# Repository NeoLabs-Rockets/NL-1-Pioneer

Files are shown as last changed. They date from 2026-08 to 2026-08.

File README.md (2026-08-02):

<div align="center">

# NeoLabs-Rockets NL-1 Pioneer

NeoLabs Rockets Logo

**Rocket systems by NeoLabs — The rocket to start it all**



---

[Compatible with NeoLabs-Rockets launch system](https://github.com/NeoLabs-Rockets/Launch-System) -
[Compatible with NeoLabs-Rockets launch platform](https://github.com/NeoLabs-Rockets/Launch-Platform)

---

The **NL-1 Pioneer** is the very first rocket developed under the NeoLabs-Rockets project. Designed as an affordable and modular entry point into model rocketry, it serves as the foundation for future NeoLabs rocket designs.

This version is intentionally simple and lightweight. It is currently **non-reusable** (except in special recovery situations), as it does not yet include a parachute or other dedicated recovery system. The focus is on providing an easy-to-build, reliable platform for learning, testing, and future upgrades.

The rocket is designed to be **modular**, **low-cost**, and **easy to extend** with future payloads or recovery systems. Most parts are **print-in-place**, minimizing assembly effort while keeping the design accessible for anyone with a standard 3D printer.

</div>

<div align="center">
  
# Compatible with the following motors

| Manufacturer | Motors |
|---|---|
| Estes | 1/2A6-2, A8-3, B4-2, B6-4, B6-6, C5-3, C6-3, C6-5, C6-7 |
| Quest | A6-4, A8-3, B6-2, B6-4, C6-3, C6-5 |
| Klima | B2, B4, C6 |
| AeroTech (Q-Jet) | C12, C18, D10, D13, D20 *(some variants may be slightly longer than 70 mm)* |

</div>

# Print Settings

* **Material:** ABS is recommended for improved heat resistance and durability. PLA+ also works well for normal use.
* **Infill:** The lower, the better. **5%** is recommended to reduce weight while maintaining sufficient strength.
* **Orientation:** Print the model vertically for the best structural performance.
* **Supports:** Enable normal supports (Auto) with a **5° overhang angle**.

<div align="center">




</div>

---

<div align="center">

*Made with ❤️ by [Neo](https://github.com/neooriginal) · [NeoLabs Systems](https://github.com/NeoLabs-Systems)*

</div>

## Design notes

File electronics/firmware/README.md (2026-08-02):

# NL-1 Pioneer — Onboard Rocket Computer Firmware

Firmware for the **Seeed Studio XIAO ESP32-S3 Sense** flight computer on the NeoLabs NL-1 Pioneer. It records video and full telemetry to microSD, detects flight phases, and talks to the Mission Dashboard over a **second, independent BLE link**.

**This device never fires a motor, igniter, or any pyrotechnic.** Ignition remains exclusively with the Launch Controller.

## Hardware (from `connections.md` + schematic)

| Item | Detail |
|---|---|
| MCU | Seeed XIAO ESP32-S3 Sense (8 MB PSRAM) |
| IMU | Adafruit LSM6DSO32 (U3) |
| Baro | Adafruit BMP580 (U2) |
| I2C | SDA **GPIO5 (D4)**, SCL **GPIO6 (D5)** @ 400 kHz |
| Camera | Onboard OV2640/OV3660 (Sense expansion) |
| microSD | Onboard SPI: CS GPIO21, MOSI GPIO9, MISO GPIO8, SCK GPIO7 |
| Power | Battery → SW1 → BAT+ / BAT− |
| Battery ADC | **Not present** on schematic — not measured |

Unused sensor pins (CS, SDO, INT1/2) are left open per `connections.md`.

## Build & flash

```bash
cd electronics/firmware
pio run -e xiao_esp32s3_sense
pio run -e xiao_esp32s3_sense -t upload
pio device monitor -b 115200
```

Requirements: PlatformIO, USB cable, board in download mode if needed (BOOT + RESET).

### OTA (Bluetooth)

Same protocol shape as the Launch Controller:

| Char | UUID |
|---|---|
| OTA control | `9c4e0007-…` |
| OTA data | `9c4e0008-…` |
| OTA status | `9c4e0009-…` |

- Blocked while recording or in flight
- SHA-256 verified; device reboots after `finish`
- Dashboard: **Settings → Rocket Computer Firmware → Check & Update RC**
- CI: `.github/workflows/rc-firmware.yml` builds and publishes the rolling `rc-firmware-latest` release
- Mission Dashboard pulls from `RC_FIRMWARE_GITHUB_REPOSITORY` / `RC_FIRMWARE_RELEASE_TAG` (defaults: `NeoLabs-Rockets/NL-1-Pioneer` + `rc-firmware-latest`)

Base version: `firmware-version.txt` (CI appends `+<sha12>`).

### Host unit tests

```bash
pio test -e native_tests
```

## Architecture

```
sensor task (100 Hz)  →  flight detect  →  mission FSM
                      →  telemetry queue →  storage task → microSD
camera task           →  JPEG frames    →  storage task → video.mjpg
BLE (NimBLE)          →  command queue  →  mission FSM
                      ←  status / telemetry notifies
```

Priorities: **sensors > storage > camera/mission > BLE live telemetry**.

Modules under `src/` / `include/`:

| Module | Role |
|---|---|
| `time_manager` | Monotonic time + optional external sync |
| `mission_fsm` | Mission / recording state machine |
| `flight_detect` | Multi-criteria phase detection |
| `sensors` | LSM6DSO32 + BMP580 + MCU temp |
| `storage` | Single SD writer, session files |
| `camera_recorder` | Profiled JPEG capture with fallback |
| `ble_server` / `command_handler` | Protocol + idempotent commands |
| `event_log` | Async events.jsonl lines |

## BLE

- Device name: `NeoLabs Rocket Computer`
- Service UUID: `9c4e0001-6a2b-4c8d-9e1f-1d6c7a0b2000`  
  (Launch Controller uses `8f3a0001-…` — **separate**.)
- Command JSON (same spirit as Launch System): `{"cmd":"arm","sid":"…","seq":N}`
- File export (chunked): characteristic `9c4e0006-…` + commands `list_flights`, `list_files`, `file_begin`, `file_read`, `file_close`, `delete_flight`
- Mission Dashboard **RC Data** tab downloads a flight as ZIP over BLE, then can delete it on-device

See [docs/BLE_PROTOCOL.md](docs/BLE_PROTOCOL.md).

## Recording timeline

```
IDLE → ARM → session + video + telemetry start
     → countdown (optional) + expected ignition time
     → sensor liftoff → ascent / coast / apogee / descent
     → multi-criteria LANDING → +30 s → flush & close
```

- BLE disconnect **never** stops recording or countdown.
- `STOP_RECORDING` / `RESET` rejected during flight.
- Hard safety cap: **10 minutes** max recording if landing never confirms.
- Post-landing: **30 seconds**.

## Documentation index

- [docs/HARDWARE.md](docs/HARDWARE.md)
- [docs/ARCHITECTURE.md](docs/ARCHITECTURE.md)
- [docs/BLE_PROTOCOL.md](docs/BLE_PROTOCOL.md)
- [docs/STATE_MACHINE.md](docs/STATE_MACHINE.md)
- [docs/FLIGHT_DETECTION.md](docs/FLIGHT_DETECTION.md)
- [docs/CAMERA.md](docs/CAMERA.md)
- [docs/STORAGE.md](docs/STORAGE.md)
- [docs/DASHBOARD.md](docs/DASHBOARD.md)
- [docs/TESTING.md](docs/TESTING.md)
- [docs/ERROR_CODES.md](docs/ERROR_CODES.md)

## Dashboard

Mission Dashboard (`~/NeoLabs-Rockets/MissionDashboard`) was extended with:

- `rocket-ble-link.js` — independent GATT connection manager
- `rocket-computer.js` — UI + command mirroring
- Arm / countdown / abort on the launch console also notify the rocket computer when linked

## Safety

| Action | Rocket computer |
|---|---|
| Ignition / relay | **Never** |
| Pyro / servo deploy | **Never** |
| Video + telemetry | Yes |
| Flight phase log | Yes |
| Live BLE status | Yes (best-effort) |

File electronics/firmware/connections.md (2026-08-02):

esp32:

&#x20; board: Seeed XIAO ESP32-S3 Sense

power:

&#x20; "ESP32 3V3":

&#x20;   - "BMP580 VIN"

&#x20;   - "LSM6DSO32 VIN"

&#x20; "ESP32 GND":

&#x20;   - "BMP580 GND"

&#x20;   - "LSM6DSO32 GND"

i2c:

&#x20; "ESP32 D4 (GPIO5 / SDA)":

&#x20;   - "BMP580 SDA"

&#x20;   - "LSM6DSO32 SDA"

&#x20; "ESP32 D5 (GPIO6 / SCL)":

&#x20;   - "BMP580 SCL"

&#x20;   - "LSM6DSO32 SCL"

battery:

&#x20; "Battery +":

&#x20;   - "Switch COM"

&#x20; "Switch NO":

&#x20;   - "ESP32 BAT+"

&#x20; "Battery -":

&#x20;   - "ESP32 BAT-"

unused:

&#x20; - "BMP580 3Vo"

&#x20; - "BMP580 CS"

&#x20; - "BMP580 SDO"

&#x20; - "LSM6DSO32 INT1"

&#x20; - "LSM6DSO32 INT2"

&#x20; - "LSM6DSO32 CS"

&#x20; - "LSM6DSO32 SDO"

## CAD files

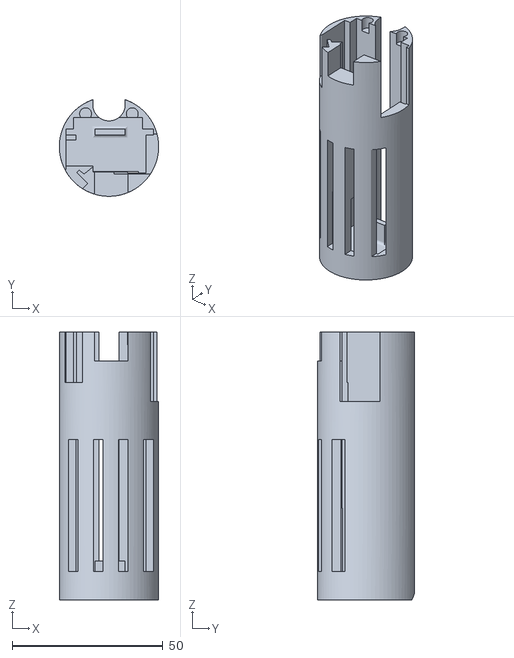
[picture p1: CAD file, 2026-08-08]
electronics/NL1-ElectronicMount.stl
33.0 x 32.1 x 89.0

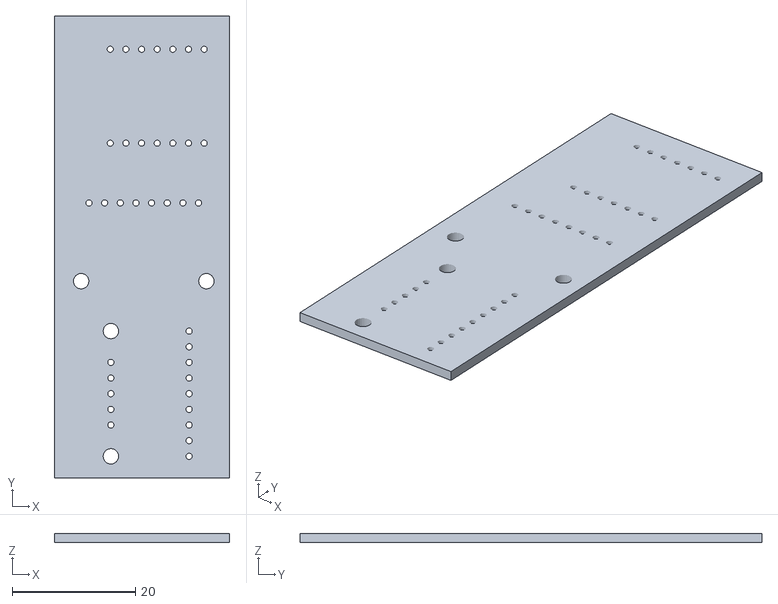
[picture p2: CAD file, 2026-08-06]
electronics/onboard-systems/pcb.stl
28.4 x 74.9 x 1.51

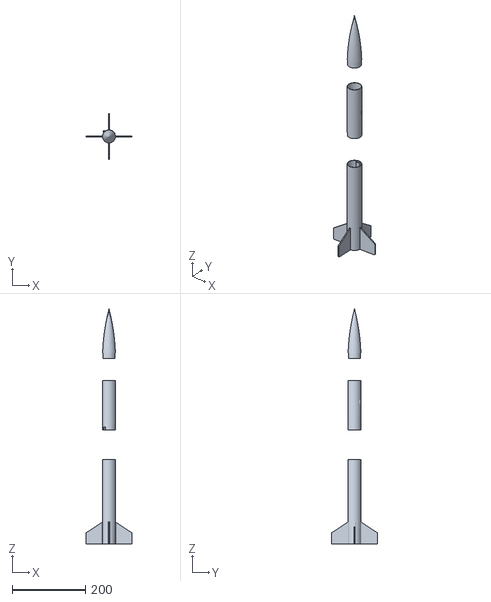
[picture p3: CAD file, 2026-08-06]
NL-1 Pioneer.stl
126.0 x 126.0 x 640.0

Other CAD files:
NL-1-Pioneer.f3d

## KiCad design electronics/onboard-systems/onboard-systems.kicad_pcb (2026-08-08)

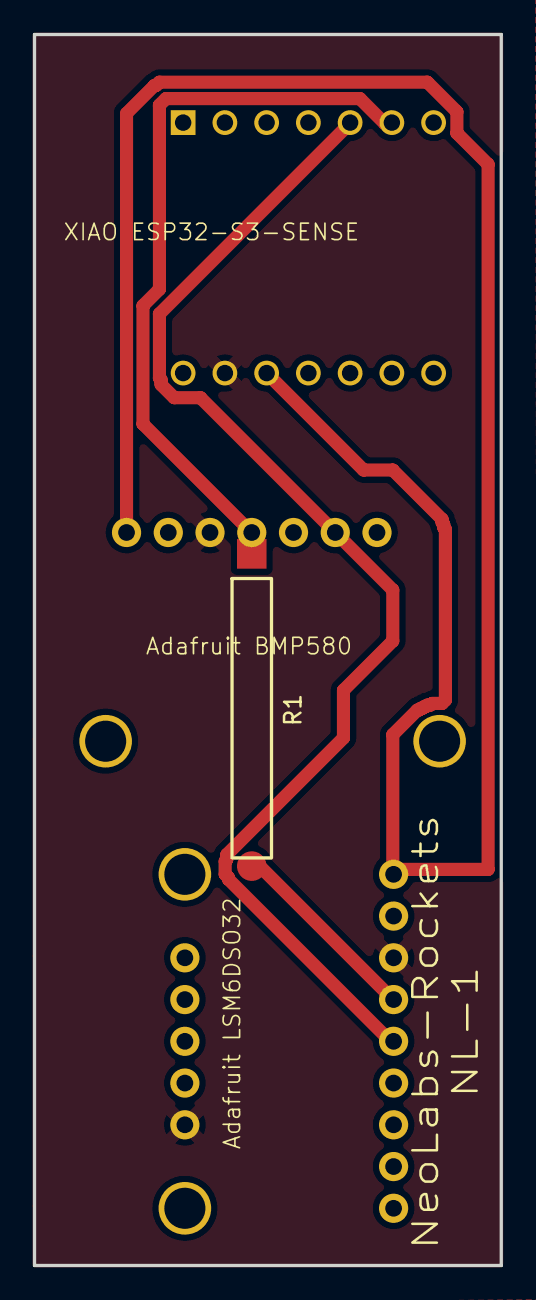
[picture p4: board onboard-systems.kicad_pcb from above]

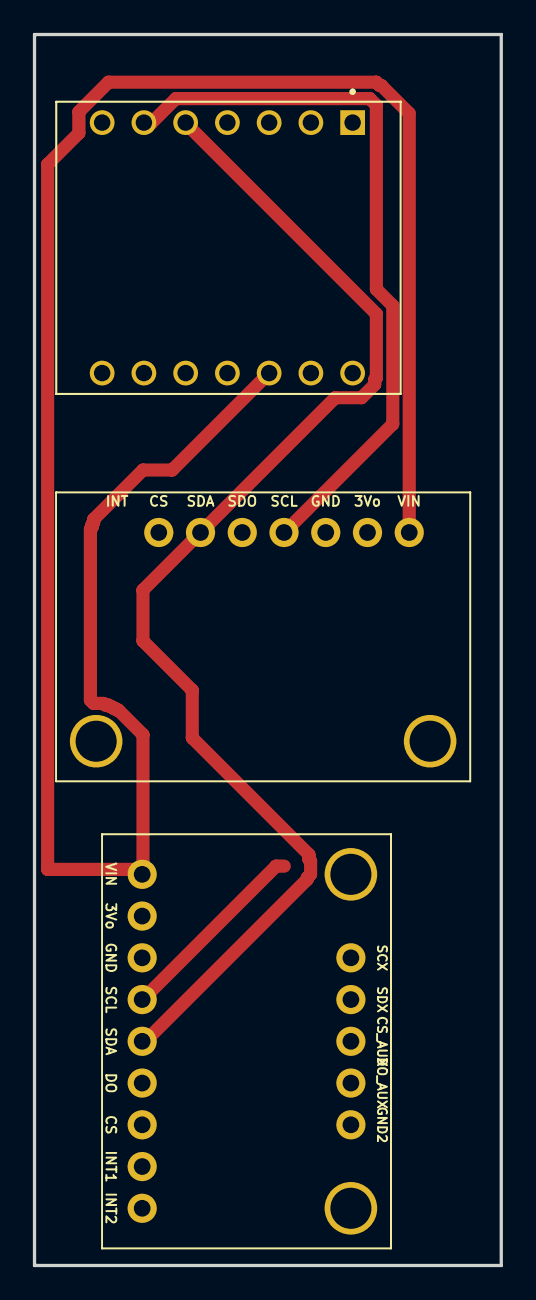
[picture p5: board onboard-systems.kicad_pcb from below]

Board: 2 copper layers, 28.4 x 74.9 mm, 4 parts (3 on the bottom side), 4 nets.

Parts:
R1: 0R; R_0R_THT_Custom
U1: XIAO_ESP32_S3; MODULE_XIAO_ESP32_S3
U2: Adafruit_BMP580; Adafruit_BMP580_Breakout
U3: Adafruit_LSM6DSO32; Adafruit_LSM6DSO32_Breakout

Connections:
GND: U1.13 (GND), U2.3 (GND), U3.3 (GND), U3.14 (GND2)
unnamed: U1.12 (3V3), U2.1 (VIN), U3.1 (VIN)
unnamed: U1.5 (D4/GPIO5), U2.6 (SDA), U3.5 (SDA)
unnamed: R1.1, U1.6 (D5/GPIO6), U2.4 (SCL), U3.4 (SCL)

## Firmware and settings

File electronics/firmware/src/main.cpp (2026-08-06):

/**
 * NeoLabs NL-1 Pioneer — Onboard Rocket Computer
 *
 * Records video + telemetry to microSD. Communicates with Mission Dashboard
 * over BLE. Never controls ignition or pyrotechnics.
 *
 * Hardware (connections.md + schematic):
 *   Seeed XIAO ESP32-S3 Sense
 *   BMP580 + LSM6DSO32 on I2C GPIO5/GPIO6
 *   Onboard camera + microSD
 */

#include <Arduino.h>
#include <esp_task_wdt.h>
#include <esp_system.h>

#include "config.h"
#include "board_pins.h"
#include "types.h"
#include "time_manager.h"
#include "event_log.h"
#include "mission_fsm.h"
#include "mission_fsm_internal.h"
#include "sensors.h"
#include "flight_detect.h"
#include "storage.h"
#include "camera_recorder.h"
#include "ble_server.h"
#include "ota_service.h"
#include "crc16.h"

static SensorSnapshot g_sensors{};
static SystemSnapshot g_system{};
static portMUX_TYPE g_snap_mux = portMUX_INITIALIZER_UNLOCKED;

// ── Status LED (XIAO amber user LED, GPIO21, active-low) ────────────────────
// On Sense, GPIO21 is also microSD CS. Never drive it as an LED — any
// pre-mount bit-banging of CS contributes to "Card Failed! cmd: 0x00".
#if USER_LED_AVAILABLE
static void statusLedInit() {}
static void statusLedBootFlash() {}
static void statusLedReleaseForSd() {
  // Leave CS idle high before Storage::begin claims it.
  pinMode(PIN_SD_CS, OUTPUT);
  digitalWrite(PIN_SD_CS, HIGH);
}
static void statusLedHeartbeat() {}
#else
static void statusLedInit() {}
static void statusLedBootFlash() {}
static void statusLedReleaseForSd() {}
static void statusLedHeartbeat() {}
#endif

static void fillSystemSnapshot() {
  CameraRecorder::Stats cs = CameraRecorder::stats();
  g_system.mission = MissionFsm::state();
  g_system.recording = MissionFsm::recordingState();
  g_system.storage = Storage::state();
  g_system.bluetooth = BleServer::state();
  g_system.camera = CameraRecorder::state();
  g_system.phase = FlightDetect::phase();
  g_system.uptime_ms = static_cast<uint32_t>(TimeManager::monoMs());
  g_system.countdown_left_ms = MissionFsm::countdownRemainingMs(TimeManager::monoMs());
  g_system.expected_ignition_mono_ms = MissionFsm::expectedIgnitionMonoMs();
  g_system.actual_liftoff_mono_ms = MissionFsm::actualLiftoffMonoMs();
  g_system.frames_written = cs.frames_written;
  g_system.frames_dropped = cs.frames_dropped;
  g_system.actual_fps = cs.actual_fps;
  g_system.free_sd_bytes = Storage::freeBytes();
  g_system.session_bytes = 0;
  g_system.camera_profile = static_cast<uint8_t>(cs.profile);
  g_system.ground_test = false;
  g_system.last_error[0] = '\0';
  g_system.last_warning[0] = '\0';
}

static void buildTelemetryRecord(TelemetryRecord& rec, uint32_t seq) {
  TimeStamp ts = TimeManager::now();
  memset(&rec, 0, sizeof(rec));
  rec.magic = TELEM_MAGIC;
  rec.version = 1;
  rec.size = sizeof(TelemetryRecord);
  rec.mono_us = ts.mono_us;
  rec.session_us = ts.session_us;
  rec.sync_unix_ms = ts.sync_unix_ms;
  portENTER_CRITICAL(&g_snap_mux);
  rec.ax = g_sensors.ax;
  rec.ay = g_sensors.ay;
  rec.az = g_sensors.az;
  rec.gx = g_sensors.gx;
  rec.gy = g_sensors.gy;
  rec.gz = g_sensors.gz;
  rec.accel_mag = g_sensors.accel_mag;
  rec.pressure_pa = g_sensors.pressure_pa;
  rec.altitude_m = g_sensors.altitude_m;
  rec.vert_vel_ms = g_sensors.vert_vel_ms;
  rec.temp_bmp_c = g_sensors.temps[0].valid ? g_sensors.temps[0].celsius : NAN;
  rec.temp_imu_c = g_sensors.temps[1].valid ? g_sensors.temps[1].celsius : NAN;
  rec.temp_mcu_c = g_sensors.temps[2].valid ? g_sensors.temps[2].celsius : NAN;
  uint8_t flags = 0;
  if (g_sensors.imu_health == SensorHealth::OK) flags |= 1;
  if (g_sensors.baro_health == SensorHealth::OK) flags |= 2;
  if (CameraRecorder::state() == CameraState::RECORDING
      || CameraRecorder::state() == CameraState::READY
      || CameraRecorder::state() == CameraState::FALLBACK) flags |= 4;
  if (Storage::state() == StorageState::MOUNTED || Storage::state() == StorageState::WRITING) flags |= 8;
  portEXIT_CRITICAL(&g_snap_mux);
  rec.mission_state = static_cast<uint8_t>(MissionFsm::state());
  rec.recording_state = static_cast<uint8_t>(MissionFsm::recordingState());
  rec.flight_phase = static_cast<uint8_t>(FlightDetect::phase());
  rec.flags = flags;
  CameraRecorder::Stats cs = CameraRecorder::stats();
  rec.frame_count = cs.frames_written;
  rec.actual_fps_x10 = static_cast<uint16_t>(cs.actual_fps * 10.f);
  rec.dropped_frames = static_cast<uint16_t>(min(cs.frames_dropped, 65535u));
  rec.free_sd_kb = static_cast<uint32_t>(Storage::freeBytes() / 1024ULL);
  rec.seq = seq;
  rec.crc16 = crc16_ccitt(reinterpret_cast<const uint8_t*>(&rec),
                          sizeof(TelemetryRecord) - sizeof(uint16_t));
}

static void logResetReason() {
  esp_reset_reason_t r = esp_reset_reason();
  const char* name = "UNKNOWN";
  switch (r) {
    case ESP_RST_POWERON: name = "POWERON"; break;
    case ESP_RST_SW: name = "SW"; break;
    case ESP_RST_PANIC: name = "PANIC"; break;
    case ESP_RST_INT_WDT: name = "INT_WDT"; break;
    case ESP_RST_TASK_WDT: name = "TASK_WDT"; break;
    case ESP_RST_WDT: name = "WDT"; break;
    case ESP_RST_BROWNOUT: name = "BROWNOUT"; break;
    case ESP_RST_SDIO: name = "SDIO"; break;
    default: break;
  }
  char msg[48];
  snprintf(msg, sizeof(msg), "reset_%s", name);
  EventLog::emit(EventType::RESET_REASON, msg);
  EventLog::emit(EventType::BOOT, FIRMWARE_VERSION);
}

// ── Tasks ───────────────────────────────────────────────────────────────────

static void sensorTask(void*) {
  // Subscribe before the loop: esp_task_wdt_reset() is a no-op (ESP_ERR_NOT_FOUND)
  // for any task that was never added, so an unsubscribed task is unmonitored.
  esp_task_wdt_add(nullptr);
  const TickType_t period = pdMS_TO_TICKS(1000 / SENSOR_HZ_IMU);
  TickType_t last = xTaskGetTickCount();
  uint32_t telem_div = 0;
  uint32_t seq = 0;
  for (;;) {
    SensorSnapshot s;
    if (Sensors::sample(s)) {
      portENTER_CRITICAL(&g_snap_mux);
      g_sensors = s;
      portEXIT_CRITICAL(&g_snap_mux);

      bool care = MissionFsm::countdownActive()
                  || MissionFsm::state() == MissionState::ARMED
                  || MissionFsm::state() == MissionState::RECORDING
                  || MissionFsm::state() == MissionState::COUNTDOWN
                  || MissionFsm::state() == MissionState::IGNITION_EXPECTED
                  || MissionFsm::hasLiftedOff();
      if (FlightDetect::update(s, MissionFsm::expectedIgnitionMonoMs(), care)) {
        MissionFsm::setFlightPhase(FlightDetect::phase(), "sensor");
      }

      // Log telemetry at TELEMETRY_LOG_HZ when session open
      telem_div++;
      if (telem_div >= (SENSOR_HZ_IMU / TELEMETRY_LOG_HZ)) {
        telem_div = 0;
        if (Storage::isSessionOpen()) {
          TelemetryRecord rec;
          buildTelemetryRecord(rec, seq++);
          Storage::enqueueTelemetry(rec);
        }
      }
    }
    esp_task_wdt_reset();
    vTaskDelayUntil(&last, period);
  }
}

static void storageTask(void*) {
  esp_task_wdt_add(nullptr);
  for (;;) {
    // Session start/stop driven by mission flags
    char reason[40];
    if (MissionFsm::consumeStartRecording(reason, sizeof(reason))) {
      if (!Storage::isSessionOpen()) {
        if (Storage::openSession(reason)) {
          CameraRecorder::start();
          MissionFsm::markRecordingActive();
        } else {
          MissionFsm::markRecordingFailed();
          EventLog::emit(EventType::STORAGE_FAULT, "session_open_failed");
        }
      } else {
        // Idempotent — already recording
        MissionFsm::markRecordingActive();
      }
    }
    if (MissionFsm::consumeStopRecording()) {
      CameraRecorder::stop();
      Storage::closeSession("stop");
      MissionFsm::markRecordingStopped();
    }
    Storage::taskLoop();
    esp_task_wdt_reset();
    vTaskDelay(pdMS_TO_TICKS(5));
  }
}

static void cameraTask(void*) {
  esp_task_wdt_add(nullptr);
  for (;;) {
    if (CameraRecorder::isRecording()) {
      CameraRecorder::service();
    }
    esp_task_wdt_reset();
    vTaskDelay(pdMS_TO_TICKS(5));
  }
}

static void missionTask(void*) {
  esp_task_wdt_add(nullptr);
  uint32_t last_status_ms = 0;
  for (;;) {
    BleServer::serviceCommands();
    OtaService::loop();
    MissionFsm::tick(TimeManager::monoMs());

    fillSystemSnapshot();

    uint32_t now = static_cast<uint32_t>(TimeManager::monoMs());
    SensorSnapshot sensors;
    portENTER_CRITICAL(&g_snap_mux);
    sensors = g_sensors;
    portEXIT_CRITICAL(&g_snap_mux);

    // Status every 1 s; telemetry at configured rate
    if (now - last_status_ms >= 1000) {
      last_status_ms = now;
      BleServer::publishStatus(g_system, sensors);
    }
    BleServer::publishTelemetry(sensors, g_system);

    // Shed BLE telemetry rate if SD is falling behind (simple heuristic)
    CameraRecorder::Stats cs = CameraRecorder::stats();
    if (cs.frames_dropped > 0 && cs.frames_written > 0
        && cs.frames_dropped * 10 > cs.frames_written) {
      BleServer::setTelemetryHz(BLE_TELEMETRY_HZ_MIN);
    }

    esp_task_wdt_reset();
    vTaskDelay(pdMS_TO_TICKS(20));
  }
}

void setup() {
  Serial.begin(115200);
  delay(200);
  Serial.printf("\n[NL1] Rocket Computer %s\n", FIRMWARE_VERSION);

  // Visual proof-of-life before SD claims GPIO21 as CS.
  statusLedInit();
  statusLedBootFlash();

  TimeManager::begin();
  EventLog::begin();
  MissionFsm::begin();
  MissionFsm::advanceFromBoot();
  logResetReason();

  // Task watchdog (timeout seconds, panic on trip)
  esp_task_wdt_init(WDT_TIMEOUT_S, true);
  esp_task_wdt_add(NULL);

  // Release GPIO21 to SD CS before mounting the card.
  statusLedReleaseForSd();
  bool sd_ok = Storage::begin();

  // Camera SCCB (pins 39/40) shares the ESP32-S3 I2C controller with Wire.
  // If sensors are brought up first, esp_camera_init() leaves external I2C
  // (GPIO5/6) broken — scan/begin OK, then continuous Wire Error -1.
  // Init camera first, then external sensors on Wire.
  bool cam_ok = CameraRecorder::begin();
  bool sens_ok = Sensors::begin();
  FlightDetect::begin();
  BleServer::begin();

  if (!sens_ok) EventLog::emit(EventType::WARNING, "no_sensors");
  if (!sd_ok) EventLog::emit(EventType::WARNING, "no_sd");
  if (!cam_ok) EventLog::emit(EventType::WARNING, "no_camera");

  // Self-test complete — enter IDLE even if some peripherals missing (degraded)
  MissionFsm::advanceSelfTestOk();

  xTaskCreatePinnedToCore(sensorTask, "sensor", 6144, nullptr, PRIO_SENSOR, nullptr, 1);
  xTaskCreatePinnedToCore(storageTask, "storage", 8192, nullptr, PRIO_STORAGE, nullptr, 1);
  xTaskCreatePinnedToCore(cameraTask, "camera", 8192, nullptr, PRIO_CAMERA, nullptr, 0);
  xTaskCreatePinnedToCore(missionTask, "mission", 8192, nullptr, PRIO_MISSION, nullptr, 0);

  Serial.println("[NL1] ready — advertising as NeoLabs Rocket Computer");
  Serial.printf("[NL1] SD=%d (free=%llu MB) IMU=%d BARO=%d CAM=%d\n",
                sd_ok,
                static_cast<unsigned long long>(Storage::freeBytes() / (1024ULL * 1024ULL)),
                Sensors::imuPresent(), Sensors::baroPresent(), cam_ok);
  Serial.printf("[NL1] storage_state=%d camera_state=%d\n",
                static_cast<int>(Storage::state()),
                static_cast<int>(CameraRecorder::state()));
}

void loop() {
  statusLedHeartbeat();
  OtaService::loop();
  esp_task_wdt_reset();
  vTaskDelay(pdMS_TO_TICKS(20));
}

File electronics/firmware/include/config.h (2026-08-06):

#pragma once
/**
 * Central configuration for NL-1 onboard rocket computer.
 * Thresholds, rates, camera profiles, and safety timeouts live here.
 */

#include <stddef.h>
#include <stdint.h>
#include "board_pins.h"

#ifndef FIRMWARE_VERSION
#define FIRMWARE_VERSION "1.0.0"
#endif

#define PROTOCOL_VERSION_MAJOR 1
#define PROTOCOL_VERSION_MINOR 0

// ── Task priorities (higher = more important) ───────────────────────────────
// Priority order from requirements:
//   1 sensors  2 storage  3 video  4 state machine  5 BLE telemetry
static constexpr uint8_t PRIO_SENSOR   = 5;
static constexpr uint8_t PRIO_STORAGE  = 4;
static constexpr uint8_t PRIO_CAMERA   = 3;
static constexpr uint8_t PRIO_MISSION  = 3;
static constexpr uint8_t PRIO_BLE      = 2;
static constexpr uint8_t PRIO_WATCHDOG = 1;

// ── Sampling rates ──────────────────────────────────────────────────────────
static constexpr uint32_t SENSOR_HZ_IMU       = 100;  // LSM6DSO32 sample target
static constexpr uint32_t SENSOR_HZ_BARO      = 50;   // BMP580 sample target
static constexpr uint32_t SENSOR_HZ_TEMP_MCU  = 1;
static constexpr uint32_t TELEMETRY_LOG_HZ    = 50;   // written to SD
static constexpr uint32_t BLE_TELEMETRY_HZ    = 5;    // live stream (degrades first)
static constexpr uint32_t BLE_TELEMETRY_HZ_MIN = 1;

// ── Camera profiles (highest stable first; runtime may fall back) ───────────
// "Max" is not the nominal peak resolution — it is the highest stable combo of
// resolution × fps × JPEG quality under concurrent sensor+SD+BLE load.
// Default primary profile: SVGA 800×600 @ 12 fps, JPEG quality 12, 2 FB in PSRAM.
// Expected data rate ≈ 0.4–0.9 MB/s depending on scene complexity.
enum class CameraProfileId : uint8_t {
  Primary_SVGA_12 = 0,
  Fallback_VGA_10 = 1,
  Low_QVGA_10     = 2,
  Count
};

// frame sizes match esp32-camera framesize_t
#define CAM_FRAMESIZE_SVGA  8   // 800x600
#define CAM_FRAMESIZE_VGA   6   // 640x480
#define CAM_FRAMESIZE_QVGA  5   // 320x240

// ── Recording / mission timeouts ────────────────────────────────────────────
// Model rocket motor burn + coast for NL-1 class motors is typically < 30 s.
// Conservative max flight window before force-stop if landing never confirms.
static constexpr uint32_t POST_LANDING_RECORD_MS     = 30000;   // +30 s after LANDED
static constexpr uint32_t MAX_MISSION_RECORD_MS      = 600000;  // 10 min hard safety cap
static constexpr uint32_t RECORDING_LEAD_BEFORE_IGN_MS = 30000;  // must be recording ≥30 s before ign
static constexpr uint32_t SD_FLUSH_INTERVAL_MS        = 1000;
static constexpr uint32_t SD_MIN_FREE_BYTES           = 32UL * 1024UL * 1024UL;  // refuse new session if <32 MB

// ── Flight phase detection (multi-criteria, hysteresis) ─────────────────────
// Accelerations in m/s², rates in deg/s, altitudes in m, velocities in m/s.
struct FlightDetectConfig {
  float liftoffAccelMagMs2;
  float liftoffAxialDeltaMs2;
  uint32_t liftoffMinMs;
  float burnoutAccelMs2;
  uint32_t burnoutMinMs;
  float apogeeVertVelMs;
  float apogeeAltWindowM;
  uint32_t apogeeMinMs;
  float descentVertVelMs;
  float impactAccelMagMs2;
  uint32_t impactWindowMs;
  float landedAccelBandMs2;
  float landedGyroMaxDps;
  float landedAltStdM;
  float landedVertVelMs;
  uint32_t landedConfirmMs;
  float minFlightAltGainM;
};

static constexpr FlightDetectConfig kFlightCfg = {
  /*liftoffAccelMagMs2*/   18.0f,
  /*liftoffAxialDeltaMs2*/ 12.0f,
  /*liftoffMinMs*/         80,
  /*burnoutAccelMs2*/      14.0f,
  /*burnoutMinMs*/         150,
  /*apogeeVertVelMs*/      2.5f,
  /*apogeeAltWindowM*/     3.0f,
  /*apogeeMinMs*/          200,
  /*descentVertVelMs*/     -2.0f,
  /*impactAccelMagMs2*/    25.0f,
  /*impactWindowMs*/       50,
  /*landedAccelBandMs2*/   2.5f,
  /*landedGyroMaxDps*/     15.0f,
  /*landedAltStdM*/        1.5f,
  /*landedVertVelMs*/      1.0f,
  /*landedConfirmMs*/      2500,
  /*minFlightAltGainM*/    5.0f,
};
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

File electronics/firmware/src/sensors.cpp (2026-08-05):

#include "sensors.h"
#include "board_pins.h"
#include "time_manager.h"
#include "event_log.h"
#include "config.h"

#ifndef UNIT_TEST
#include <Wire.h>
#include <Adafruit_LSM6DSO32.h>
#include <Adafruit_BMP5xx.h>
#include <esp_system.h>
#endif

#include <math.h>
#include <string.h>

namespace Sensors {
namespace {

#ifndef UNIT_TEST
Adafruit_LSM6DSO32 lsm;
Adafruit_BMP5xx bmp;
#endif

bool imu_ok = false;
bool baro_ok = false;
SensorHealth imu_h = SensorHealth::MISSING;
SensorHealth baro_h = SensorHealth::MISSING;

float sea_level_pa = 101325.f;
float last_alt = NAN;
uint64_t last_alt_us = 0;
float vert_vel = 0;
float filt_ax = 0, filt_ay = 0, filt_az = 0;

bool sim_enabled = false;
SensorSnapshot sim_sample{};

float pressureToAltitude(float pa) {
  // International Standard Atmosphere approximation
  return 44330.f * (1.f - powf(pa / sea_level_pa, 0.1903f));
}

#ifndef UNIT_TEST
float readMcuTempC() {
  // ESP32-S3 internal temperature sensor (°C).
  return temperatureRead();
}
#endif

}  // namespace

#ifndef UNIT_TEST
// Scan 7-bit addresses and print responders for bring-up / wiring debug.
static int i2cScanAndLog(const char* tag, int sda, int scl, uint32_t hz) {
  Wire.end();
  // Weak internal pull-ups help if external STEMMA pull-ups are missing.
  pinMode(sda, INPUT_PULLUP);
  pinMode(scl, INPUT_PULLUP);
  delay(2);
  int sda_lvl = digitalRead(sda);
  int scl_lvl = digitalRead(scl);
  Serial.printf("[NL1] I2C %s SDA=GPIO%d SCL=GPIO%d @ %lu Hz (idle SDA=%d SCL=%d, expect 1/1)\n",
                tag, sda, scl, static_cast<unsigned long>(hz), sda_lvl, scl_lvl);

  Wire.begin(sda, scl);
  Wire.setClock(hz);
  delay(20);

  int found = 0;
  for (uint8_t addr = 0x08; addr < 0x78; addr++) {
    Wire.beginTransmission(addr);
    uint8_t err = Wire.endTransmission();
    if (err == 0) {
      found++;
      const char* who = "";
      if (addr == ADDR_BMP580 || addr == ADDR_BMP580_ALT) who = " (BMP580?)";
      else if (addr == ADDR_LSM6DSO32 || addr == ADDR_LSM6DSO32_ALT) who = " (LSM6DSO32?)";
      Serial.printf("[NL1]   I2C device at 0x%02X%s\n", addr, who);
    }
  }
  if (found == 0) {
    Serial.println("[NL1]   I2C: no devices responded");
  } else {
    Serial.printf("[NL1]   I2C: %d device(s) found\n", found);
  }
  return found;
}
#endif

bool begin() {
  imu_ok = false;
  baro_ok = false;
  imu_h = SensorHealth::MISSING;
  baro_h = SensorHealth::MISSING;
  last_alt = NAN;
  vert_vel = 0;
  sim_enabled = false;

#ifndef UNIT_TEST
  // PCB nets (onboard-systems.kicad_pcb):
  //   SDA = U1 D4/GPIO5 → U2.SDA + U3.SDA
  //   SCL = U1 D5/GPIO6 → U2.SCL + U3.SCL
  //   VIN = U1 3V3
  // Try 100 kHz first (more tolerant of capacitance / weak pull-ups), then 400 kHz.
  int found = i2cScanAndLog("primary", PIN_I2C_SDA, PIN_I2C_SCL, 100000);
  if (found == 0) {
    found = i2cScanAndLog("primary-400k", PIN_I2C_SDA, PIN_I2C_SCL, I2C_FREQ_HZ);
  }
  if (found == 0) {
    // Diagnostic only: detect SDA/SCL swap on a hand-wired board.
    found = i2cScanAndLog("swapped", PIN_I2C_SCL, PIN_I2C_SDA, 100000);
    if (found > 0) {
      Serial.println("[NL1] WARNING: devices only visible with SDA/SCL swapped!");
    } else {
      // Restore primary pin map for library probes below.
      Wire.end();
      Wire.begin(PIN_I2C_SDA, PIN_I2C_SCL);
      Wire.setClock(100000);
    }
  }

  delay(50);  // allow breakouts to come out of power-on reset

  // LSM6DSO32 — try both address straps
  if (lsm.begin_I2C(ADDR_LSM6DSO32, &Wire) || lsm.begin_I2C(ADDR_LSM6DSO32_ALT, &Wire)) {
    lsm.setAccelRange(LSM6DSO32_ACCEL_RANGE_32_G);
    lsm.setGyroRange(LSM6DS_GYRO_RANGE_2000_DPS);
    lsm.setAccelDataRate(LSM6DS_RATE_104_HZ);
    lsm.setGyroDataRate(LSM6DS_RATE_104_HZ);
    imu_ok = true;
    imu_h = SensorHealth::OK;
    Serial.println("[NL1] LSM6DSO32 OK");
  } else {
    EventLog::emit(EventType::SENSOR_FAULT, "LSM6DSO32_missing");
    imu_h = SensorHealth::MISSING;
    Serial.println("[NL1] LSM6DSO32 MISSING");
  }

  // BMP580 (Adafruit_BMP5xx: pressure field is hPa after performReading)
  if (bmp.begin(ADDR_BMP580, &Wire) || bmp.begin(ADDR_BMP580_ALT, &Wire)) {
    bmp.setOutputDataRate(BMP5XX_ODR_50_HZ);
    bmp.setPowerMode(BMP5XX_POWERMODE_NORMAL);
    baro_ok = true;
    baro_h = SensorHealth::OK;
    Serial.println("[NL1] BMP580 OK");
  } else {
    EventLog::emit(EventType::SENSOR_FAULT, "BMP580_missing");
    baro_h = SensorHealth::MISSING;
    Serial.println("[NL1] BMP580 MISSING");
  }
#else
  imu_ok = true;
  baro_ok = true;
  imu_h = SensorHealth::OK;
  baro_h = SensorHealth::OK;
#endif

  return imu_ok || baro_ok;
}

void end() {}

bool sample(SensorSnapshot& out) {
  if (sim_enabled) {
    out = sim_sample;
    out.ts = TimeManager::now();
    out.valid = true;
    return true;
  }

  memset(&out, 0, sizeof(out));
  out.ts = TimeManager::now();
  out.imu_health = imu_h;
  out.baro_health = baro_h;
  out.valid = false;
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

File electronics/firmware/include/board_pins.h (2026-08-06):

#pragma once
/**
 * Hardware pin map for NL-1 Pioneer onboard rocket computer.
 *
 * Sources of truth (do not invent pins):
 *   - electronics/firmware/connections.md
 *   - electronics/onboard-systems/onboard-systems.kicad_sch
 *   - Seeed Studio XIAO ESP32-S3 Sense official pinout
 *
 * External sensors on shared I2C bus:
 *   BMP580  (U2) — pressure + temperature
 *   LSM6DSO32 (U3) — accel + gyro (+ IMU die temperature)
 *
 * Onboard Sense expansion (camera + microSD) uses fixed GPIOs documented by Seeed.
 */

#include <stdint.h>

// ── Board identity ──────────────────────────────────────────────────────────
#define BOARD_MODEL_NAME        "Seeed XIAO ESP32-S3 Sense"
#define CAMERA_MODEL_NAME       "OV2640/OV3660 (XIAO Sense expansion)"
#define HAS_PSRAM_EXPECTED      1
#define PSRAM_SIZE_BYTES_EXPECT (8 * 1024 * 1024)

// ── External I2C bus (connections.md) ───────────────────────────────────────
// ESP32 D4 = GPIO5 = SDA
// ESP32 D5 = GPIO6 = SCL
static constexpr int PIN_I2C_SDA = 5;
static constexpr int PIN_I2C_SCL = 6;
static constexpr uint32_t I2C_FREQ_HZ = 400000;

// Default 7-bit addresses for Adafruit STEMMA QT breakouts (I2C mode, SDO unused)
// Adafruit_BMP5xx: DEFAULT 0x46, ALTERNATIVE 0x47
static constexpr uint8_t ADDR_BMP580     = 0x46;
static constexpr uint8_t ADDR_BMP580_ALT = 0x47;
static constexpr uint8_t ADDR_LSM6DSO32  = 0x6A;  // Adafruit default
static constexpr uint8_t ADDR_LSM6DSO32_ALT = 0x6B;

// ── Onboard microSD (XIAO ESP32-S3 Sense) ───────────────────────────────────
// Seeed wiki: CS=GPIO21, SCK=D8/GPIO7, MISO=D9/GPIO8, MOSI=D10/GPIO9.
// Matches variants/XIAO_ESP32S3/pins_arduino.h (MOSI/MISO/SCK defaults).
// Init with default SPI + SD.begin(21) — not a custom SPIClass(FSPI).
static constexpr int PIN_SD_CS   = 21;
static constexpr int PIN_SD_MOSI = 9;   // D10
static constexpr int PIN_SD_MISO = 8;   // D9
static constexpr int PIN_SD_SCK  = 7;   // D8

// ── Onboard camera (XIAO ESP32-S3 Sense expansion) ──────────────────────────
// Confirmed against Seeed camera pin table (GPIO occupancy of Sense board).
static constexpr int CAM_PIN_PWDN  = -1;
static constexpr int CAM_PIN_RESET = -1;
static constexpr int CAM_PIN_XCLK  = 10;
static constexpr int CAM_PIN_SIOD  = 40;
static constexpr int CAM_PIN_SIOC  = 39;
static constexpr int CAM_PIN_D7    = 48;  // Y9
static constexpr int CAM_PIN_D6    = 11;  // Y8
static constexpr int CAM_PIN_D5    = 12;  // Y7
static constexpr int CAM_PIN_D4    = 14;  // Y6
static constexpr int CAM_PIN_D3    = 16;  // Y5
static constexpr int CAM_PIN_D2    = 18;  // Y4
static constexpr int CAM_PIN_D1    = 17;  // Y3
static constexpr int CAM_PIN_D0    = 15;  // Y2
static constexpr int CAM_PIN_VSYNC = 38;
static constexpr int CAM_PIN_HREF  = 47;
static constexpr int CAM_PIN_PCLK  = 13;

// ── Power ───────────────────────────────────────────────────────────────────
// Battery connects through SW1 to BAT+/BAT- (connections.md).
// No external battery ADC divider is present on the schematic — voltage
// measurement is therefore not available as a dedicated sensing path.
#define BATTERY_VOLTAGE_MEASURABLE 0

// User LED on XIAO ESP32-S3 (amber, active-low: LOW = on, HIGH = off).
// On Sense this pin is shared with microSD CS (PIN_SD_CS). Only drive the LED
// when SD is idle, and leave the pin HIGH afterward (LED off / CS deselect).
static constexpr int PIN_USER_LED = 21;
static constexpr bool USER_LED_ACTIVE_LOW = true;
#define USER_LED_AVAILABLE 1

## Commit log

2026-07-12 Update README with motor compatibility and print settings
    Added compatibility information for various motors and print settings.
2026-08-02 Add NL-1 onboard rocket computer firmware
    Add complete onboard firmware for the NL-1 Pioneer rocket computer targeting the Seeed XIAO ESP32-S3 Sense. Includes PlatformIO config, README, unit test and C++ headers/sources for core subsystems: 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
2026-08-02 Add BLE OTA, file export, and CI firmware workflow
    Add end-to-end support for over-the-air firmware and flight-data export plus CI automation. Changes include:
    - New GitHub Actions workflow (.github/workflows/rc-firmware.yml) to build PlatformIO firmware, produce a firmware.bin + manifest, upload artifact, and publish a rolling rc-firmware-latest release from main.
    - New firmware-version.txt and a Python script (scripts/create_firmware_manifest.py) that validates firmware size/sha and emits a JSON manifest compatible with OTA slot limits.
    - BLE/OTA: add ota_service.h/.cpp implementing a control/data/status OTA protocol (sha256-verified, begin/finish/abort, reboot delay), new BLE UUIDs in co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
    [config.h, main.cpp]
2026-08-02 Add .pio ignore, include stddef, rename LINE_MAX
    Ignore PlatformIO build dir, add missing <stddef.h> includes, and avoid a POSIX macro collision by renaming LINE_MAX to kEventLineMax.
    - .gitignore: add /electronics/firmware/.pio to ignore PlatformIO artifacts.
    - include/config.h and include/ota_service.h: include <stddef.h> so size_t is defined.
    - platformio.ini: remove hardcoded FIRMWARE_VERSION flag and note that it defaults in config.h or is overridden by CI.
    - src/event_log.cpp: rename LINE_MAX to kEventLineMax (with a comment about the POSIX macro), and update queue creation and local buffers to use the new constant.
    [config.h]
2026-08-05 Improve SD/LED handling and add diagnostics
    Make the board more robust and easier to debug during bring-up:
    - board_pins.h: Mark user LED available, add USER_LED_ACTIVE_LOW and detailed comment about shared SD CS (GPIO21).
    - config.h: Fix FLIGHTS_DIR to be card-root relative ("/flights") and document Arduino-esp32 VFS behavior.
    - main.cpp: Add status LED helpers that flash at boot but release the pin to SD CS before mounting; add more runtime Serial diagnostics (SD free MB, storage_state, camera_state), shorten loop delay and call a heartbeat stub.
    - camera_recorder.cpp: Log camera init success/failure with profile info for easier camera debugging.
    - sensors.cpp: Add optional I2C scan-and-l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
    [board_pins.h, camera_recorder.cpp, config.h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]
2026-08-06 Improve SD, BLE, and mission safety
    Multiple firmware improvements:
    - Storage: rewrite SD bring-up to be far more robust on XIAO ESP32-S3 Sense. Try Arduino SD path first, fall back to ESP-IDF SDSPI on SPI2/SPI3, then slow-clock fallback; rebind to Arduino SD, probe card type/size, report diagnostics, and attempt a 20 MHz speed bump. Remove custom SPIClass usage and add low-level includes. Add helper functions sdTryIdfMount/sdMountArduino and more verbose failure hints.
    - BLE/status: increase preferred ATT MTU to 512 and add BLE_NOTIFY_BUDGET to avoid silent JSON truncation. Trim status payload to fit budget, add runtime Serial warning when a status exceeds the budget, and include Arduino.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
    [board_pins.h, config.h, main.cpp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]
2026-08-06 update models
    [NL-1 Pioneer.stl, NL1-ElectronicMount.stl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]
2026-08-08 fix pcb
    [onboard-systems.kicad_pcb]
